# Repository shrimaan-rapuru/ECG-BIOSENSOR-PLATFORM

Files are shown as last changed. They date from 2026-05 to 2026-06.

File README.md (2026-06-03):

# Development and Evaluation of a Low-Cost Real-Time ECG Biosensing Platform

> Integrating Signal Processing, Robustness Analysis, and Physiological Visualization

**Shrimaan Rapuru** | The Early College at Guilford | Summer 2026
[Technical Report](report/) | [Results](results/) | [Dashboard](dashboard/)

---

## Abstract

This project investigates whether consumer-grade biosensing hardware can produce
physiologically meaningful cardiac metrics through optimized signal processing,
motivated by observed healthcare access inequality at Open Door Ministries, a
homeless shelter where I volunteer. Using a SparkFun AD8232 ECG module and Arduino
Uno R4 Minima ($102 total), I designed and validated a complete real-time ECG
acquisition and analysis pipeline. A 4th-order Butterworth bandpass filter
(0.5-40Hz) with IIR notch (60Hz) achieved visible PQRST morphology and 96.3%
mean R-peak detection accuracy across five validated resting trials. Three
structured experiments evaluated physiological response (resting vs. exercise vs.
recovery), electrode placement robustness, and comparative filter algorithm
performance. A key finding: Moving Average filtering achieves higher SNR but lower
detection reliability than Butterworth filtering, revealing that SNR alone is
insufficient to evaluate ECG filter quality. Results suggest low-cost ECG
acquisition is viable with careful signal processing methodology.

---

## Hero Figure

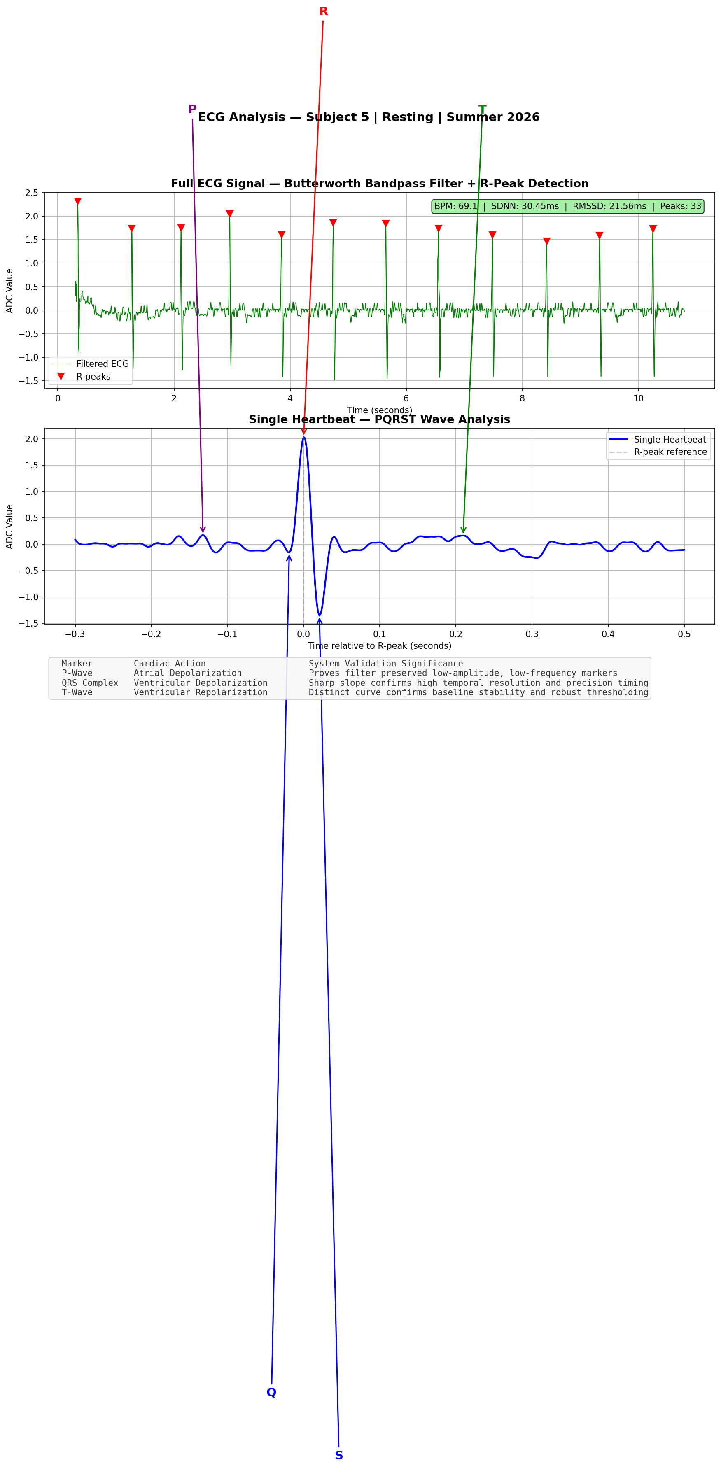
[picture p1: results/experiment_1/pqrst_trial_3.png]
PQRST Wave Analysis


*Real-time ECG signal captured at 533Hz. All 5 PQRST waves clearly identified.
BPM: 89.5 | SDNN: 17.63ms | RMSSD: 23.65ms | 42 peaks detected.*

---

## Why This Matters

Standard clinical ECG systems cost $1,000-$10,000, placing cardiac monitoring
out of reach for many individuals and resource-limited settings. This project
asks a practical engineering question: can a $102 consumer-grade system produce
physiologically meaningful cardiac metrics with careful signal processing?

The answer, supported by validated experiments, is yes. This work demonstrates
that accessibility and rigor are not mutually exclusive. The same engineering
discipline that produces expensive medical devices can be applied to low-cost
hardware to yield credible, reproducible physiological measurements.

This project was motivated by direct observation of healthcare access inequality
at Open Door Ministries, where I coordinate volunteer scheduling. Every system
I build asks the same question I first asked there: how do we build tools that
actually reach the people who need them most?

---

## Key Results

- 96.3% mean R-peak detection accuracy across 5 validated resting trials
- 20% post-exercise BPM elevation (90 to 108 BPM) with parasympathetic rebound confirmed
- All 5 PQRST waves visible: Q-wave 7.9% of R, S-wave 28.0% of R
- Single electrode displacement (+-2cm) has minimal BPM impact; combined displacement degrades accuracy 6.3%
- Moving Average achieves higher SNR but lower detection reliability than Butterworth -- confirming SNR alone is insufficient to evaluate ECG filter quality

---

## System Architecture

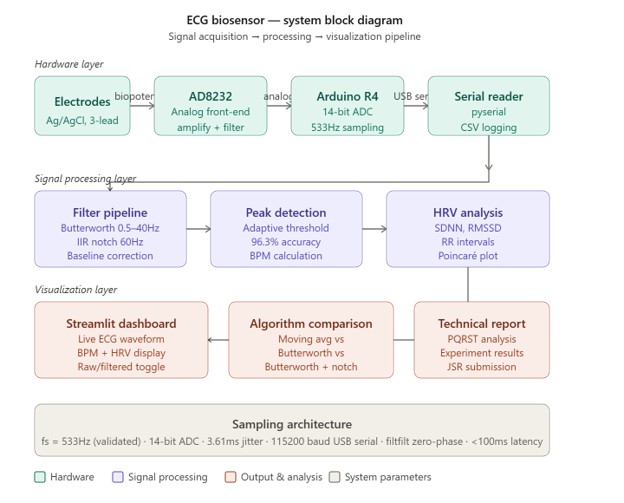
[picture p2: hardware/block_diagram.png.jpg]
Block Diagram


| Layer | Components |
|---|---|
| Hardware | AD8232 AFE -> Arduino R4 Minima (14-bit ADC, 533Hz) -> USB Serial |
| Signal Processing | Butterworth Bandpass (0.5-40Hz) + IIR Notch (60Hz) + Peak Detection |
| Analysis | BPM calculation, HRV (SDNN/RMSSD), PQRST morphology |
| Visualization | Streamlit live dashboard + Matplotlib experimental plots |

---

## Hardware

### Bill of Materials

| Component | Part Number | Cost | Purpose |
|---|---|---|---|
| SparkFun AD8232 | SEN-12650 | $24.41 | ECG analog front-end |
| Electrode Cable | CAB-12970 | $9.60 | 3-lead electrode connection |
| Arduino Uno R4 Minima | -- | $19.99 | 14-bit ADC + USB serial |
| Ag/AgCl Electrodes 100pk | Kendall | $15.30 | Skin contact |
| Breadboard + jumpers | -- | $8.99 | Prototyping |
| Alcohol prep pads | -- | $7.00 | Skin preparation |
| Header pins | HiLetgo 40-pin | $5.49 | AD8232 connection |
| **Total** | | **$90.78** | |

### Wiring

| AD8232 Pin | Arduino Pin | Function |
|---|---|---|
| 3.3V | 3.3V | Power |
| GND | GND | Ground |
| OUTPUT | A0 | ECG signal |
| LO+ | D10 | Lead-off detect + |
| LO- | D11 | Lead-off detect - |

### Hardware Photos

| | |
|---|---|
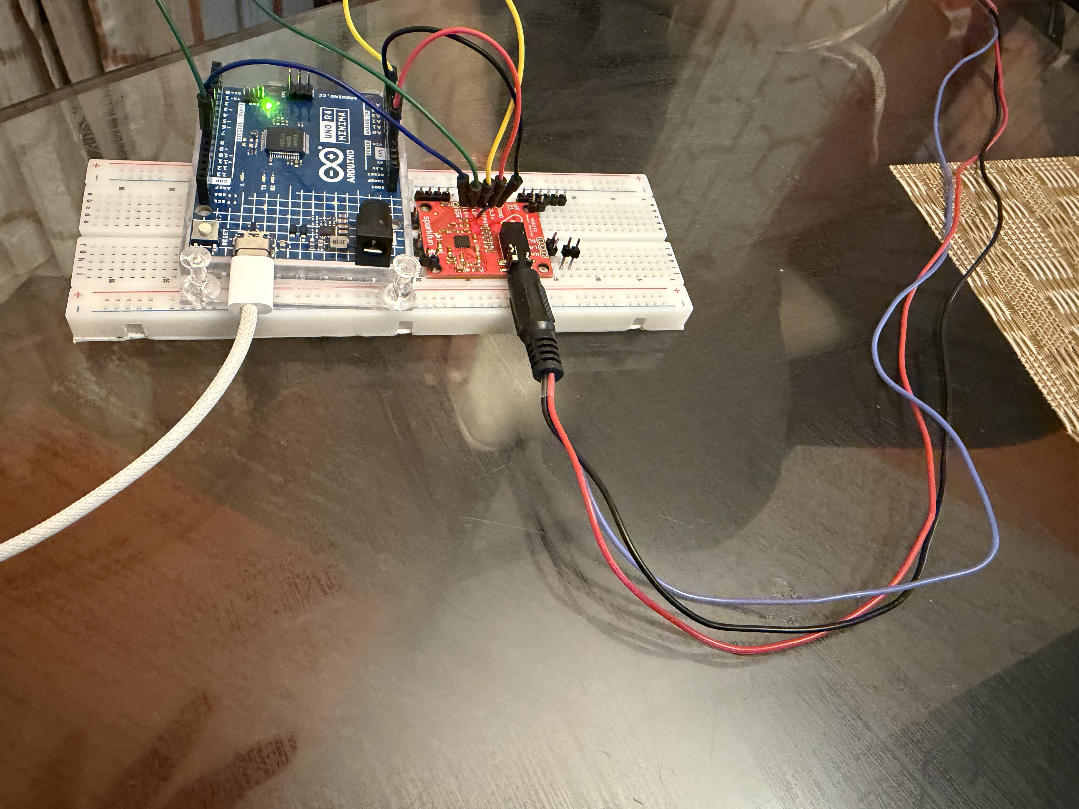
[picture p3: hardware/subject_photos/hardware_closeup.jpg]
Hardware
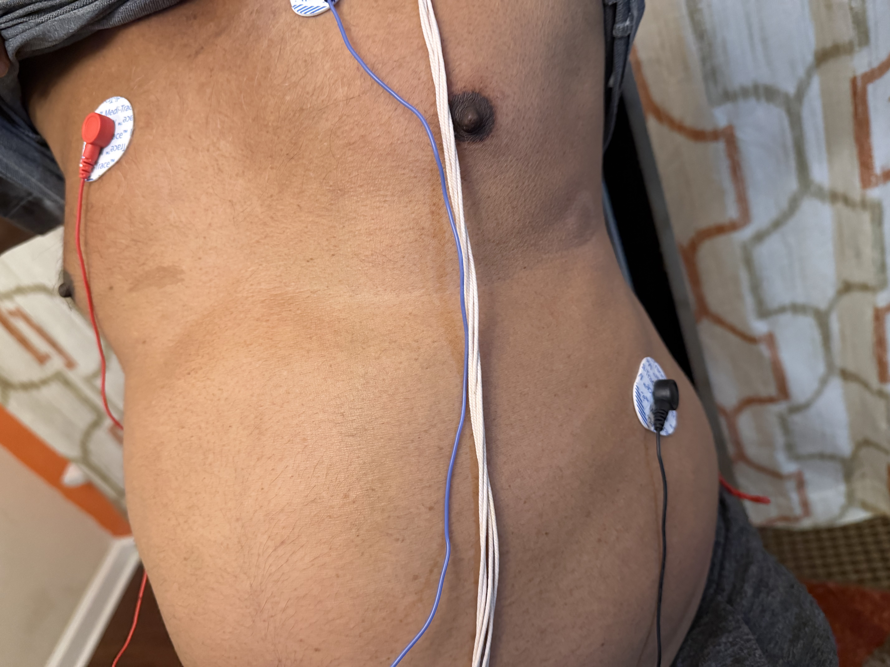
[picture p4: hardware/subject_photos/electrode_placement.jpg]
Electrodes
|  |  |
| Hardware setup — AD8232 + Arduino R4 Minima | Electrode placement on subject |
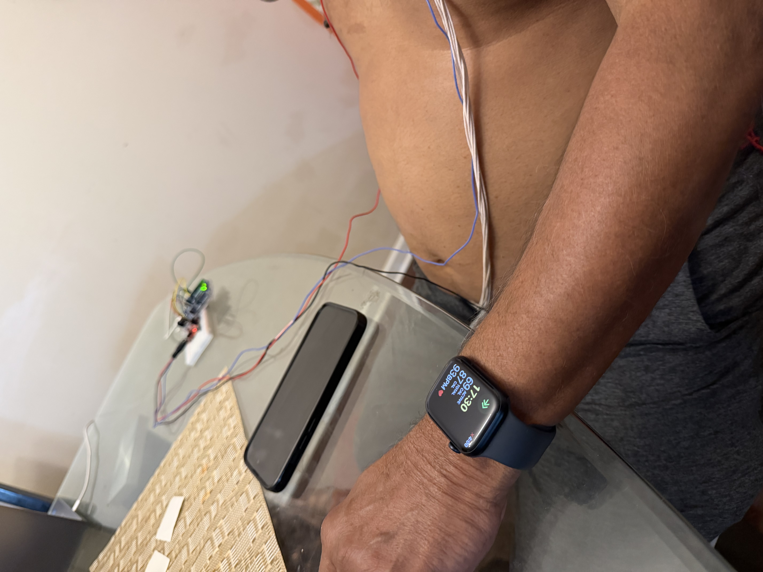
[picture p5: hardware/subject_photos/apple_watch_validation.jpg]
Validation
|  | Setup |
| Apple Watch BPM validation — simultaneous recording | Full system setup overview |
### Electrode Placement
- **Red** -> Right chest (below collarbone)
- **Blue** -> Left chest (below collarbone)
- **Black** -> Right lower abdomen (ground)

### PCB Design
Custom PCB designed in EasyEDA featuring AD8232, decoupling capacitors (2x100nF,
1x10uF), bias resistors (2x10kOhm), 3.5mm PJ-320A electrode jack, and Arduino
pin headers. All components selected from JLCPCB assembly library.
Fabrication via JLCPCB planned as Phase 2.

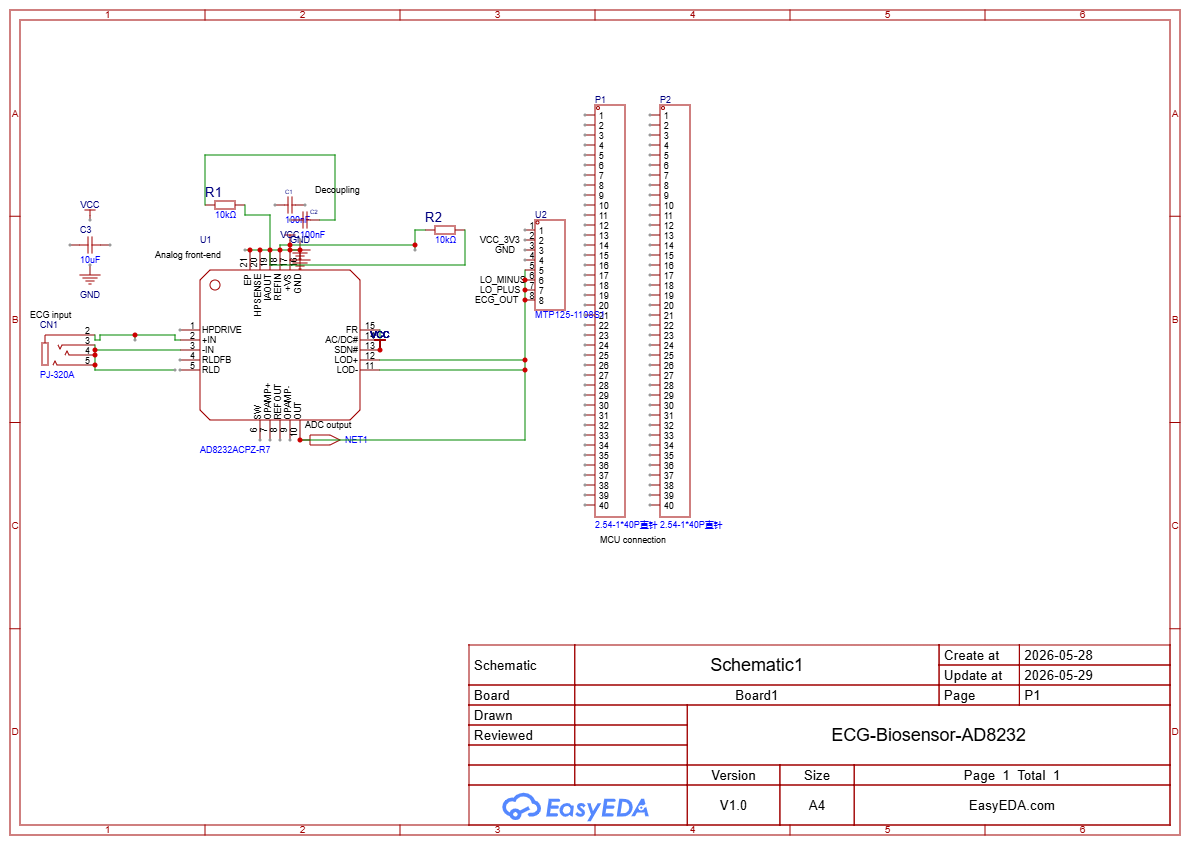
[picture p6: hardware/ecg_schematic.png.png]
Schematic


---

## Signal Processing Pipeline

### Filter Specifications

| Filter | Type | Cutoff | Order | Purpose |
|---|---|---|---|---|
| High-pass | Butterworth | 0.5 Hz | 4 | Baseline drift removal |
| Low-pass | Butterworth | 40 Hz | 4 | EMG artifact removal |
| Notch | IIR | 60 Hz | Q=30 | Powerline interference |

**Implementation:** Zero-phase filtering (scipy filtfilt) eliminates phase
distortion for accurate RR interval timing. Critical for HRV analysis where
millisecond-level timing precision determines metric validity.

**Design decision:** The 0.5 Hz lower cutoff was deliberately calibrated to
preserve the low-amplitude P-wave rather than aggressively filtering baseline
drift -- prioritizing physiological completeness over visual cleanliness.

### Sampling Architecture

| Parameter | Value |
|---|---|
| Sampling frequency | 533.3 Hz (validated -- not assumed) |
| ADC resolution | 14-bit |
| Serial baud rate | 115200 bps |
| Timing jitter | 3.61ms |
| Recording duration | 30 seconds (16,000 samples) |
| Signal inversion | Applied (electrode polarity correction) |

### Peak Detection

Adaptive threshold: median + 0.5 x std
Minimum R-R distance: 0.6 x fs (prevents double detection)
Mean accuracy: 96.3% (range: 89.4%-100.0%, N=5 trials)

### Key Signal Processing Insight

A critical finding from Experiment 3: Moving Average filtering achieved higher
mean SNR (0.63 +/- 1.99 dB) compared to Butterworth bandpass (-10.14 +/- 3.58 dB),
yet demonstrated inferior BPM consistency across trials.

This reveals a fundamental limitation of SNR as an ECG filter evaluation metric:
- Moving Average smooths broadband noise but distorts QRS morphology
- Butterworth bandpass selectively removes non-physiological frequency content
- Visually cleaner signals are not necessarily physiologically superior
- Morphology preservation matters more than signal power ratio for reliable detection

Filter Comparison

### PQRST Morphology

| Wave | Amplitude | % of R | Physiological Meaning |
|---|---|---|---|
| P | visible | -- | Atrial depolarization |
| Q | -18.0 ADC | 7.9% | Septal depolarization |
| R | 228.3 ADC | 100% | Ventricular depolarization |
| S | -64.0 ADC | 28.0% | Late ventricular depolarization |
| T | ~50 ADC | ~22% | Ventricular repolarization |

---

## Experiments

### Experiment 1 -- Resting vs Exercise vs Recovery

| State | BPM | SDNN | RMSSD |
|---|---|---|---|
| Resting avg | 91.0 | 41.31ms | 45.93ms |
| Pre-exercise | 90 | -- | -- |
| Post-exercise | 108 | -- | -- |
| Recovery 1 | 86.7 | 54.33ms | 45.45ms |
| Recovery 2 | 92.1 | 20.18ms | 9.91ms |
| Recovery 3 | 95.7 | 9.24ms | 9.42ms |

### Experiment 2 -- Electrode Placement Robustness

| Condition | Avg BPM | vs Standard |
|---|---|---|
| Standard | 82.2 | baseline |
| RA off 2cm | 81.6 | -0.7% |
| LA off 2cm | 83.0 | +1.0% |
| Both off 2cm | 87.4 | +6.3% |

### Experiment 3 -- Filter Algorithm Comparison

| Algorithm | SNR | BPM | Time |
|---|---|---|---|
| Moving Average | 0.63 +/- 1.99 dB | 88.02 +/- 8.08 | 0.69ms |
| Butterworth | -10.14 +/- 3.58 dB | 80.14 +/- 22.04 | 4.4ms |
| Butterworth+Notch | -10.16 +/- 3.58 dB | 79.7 +/- 22.92 | 2.11ms |

---

## Live Dashboard

Dashboard

**Features:**
- Real-time ECG waveform with R-peak markers
- Live BPM display (color-coded red if >100 BPM)
- SDNN and RMSSD updating in real time
- Raw vs filtered signal toggle
- Lead-off detection alert
- CSV export for offline analysis

**Run locally:**

```
cd dashboard
pip install -r requirements.txt
streamlit run ecg_dashboard.py
```

> Not a medical device. For educational and research purposes only.

---

## Installation

```
pip install streamlit pandas numpy scipy pyserial plotly matplotlib
```

Arduino setup: Install Arduino IDE 2.x, select Arduino UNO R4 Minima,
set baud rate 115200, close Serial Monitor before running Python scripts.

---

## Repository Structure

```
ecg-biosensor/
├── signal_processing/           # Python analysis scripts
│   ├── serial_reader.py         # Arduino serial data capture
│   ├── filters.py               # Butterworth + notch filter pipeline
│   ├── peak_detection.py        # R-peak detection + HRV analysis
│   ├── pqrst_analysis.py        # PQRST wave visualization
│   ├── raw_vs_filtered.py       # Normalized comparison plots
│   ├── negative_deflection.py   # Q/S wave investigation
│   ├── filter_visual_comparison.py  # 4-panel algorithm comparison
│   ├── experiment_3.py          # Algorithm benchmarking
│   ├── quick_bpm_check.py       # 10-second live BPM check
│   └── validation.py            # Peak accuracy validation
├── dashboard/                   # Streamlit live dashboard
│   ├── ecg_dashboard.py
│   └── requirements.txt
├── results/                     # All experimental data and plots
│   ├── experiment_1/            # Resting/exercise/recovery (10 trials)
│   ├── experiment_2/            # Electrode placement (12 trials)
│   └── experiment_3/            # Filter comparison (15 trials)
├── hardware/                    # PCB design and documentation
│   ├── ecg_schematic.png
│   ├── block_diagram.png
│   └── dashboard_screenshots/
└── report/                      # Technical report and references
    └── references/              # 5 peer-reviewed papers
```

---

## Limitations

- **Single subject:** All data from one subject -- findings cannot be generalized
- **Short HRV windows:** 30-second recordings below the 5-minute clinical standard
- **Motion artifact:** Post-exercise filtered-pipeline recordings were unreliable
- **SNR methodology:** Standard SNR penalizes DC attenuation -- may not reflect morphology quality
- **Breadboard connections:** Mechanical instability motivates PCB fabrication

---

## Future Work

- [ ] Custom PCB fabrication via JLCPCB (schematic complete)
- [ ] Multi-subject validation study (N>=10)
- [ ] Streamlit Cloud deployment
- [ ] 5-minute HRV recording windows
- [ ] lfilter for real-time causal filtering
- [ ] Bland-Altman analysis vs commercial pulse oximeter
- [ ] Journal of Student Research submission (August 2026)

---

## References

1. Pan, J. & Tompkins, W.J. (1985). A real-time QRS detection algorithm. IEEE Trans Biomed Eng, 32(3), 230-236.
2. Task Force of ESC & NASPE (1996). Heart rate variability standards. Circulation, 93(5), 1043-1065.
3. Serhani, M.A. et al. (2020). ECG monitoring systems review. Sensors, 20(6), 1796.
4. Kohler, B.U. et al. (2002). Software QRS detection principles. IEEE Eng Med Biol, 21(1), 42-57.
5. Christov, I.I. (2004). Real time QRS detection adaptive threshold. BioMed Eng OnLine, 3(1), 28.

---

## License

MIT License -- see LICENSE for details.

---

## About

This project was motivated by observations at Open Door Ministries, a homeless
shelter where I volunteer as scheduling coordinator. Witnessing healthcare access
inequality firsthand raised a question that drove this research: can low-cost
consumer hardware produce clinically meaningful cardiac metrics with careful
signal processing? The answer, supported by validated experiments, is yes.

> "Every project I pursue asks the same question I first asked at Open Door:
> how do we build systems that actually reach the people who need them most?"

Shrimaan Rapuru | The Early College at Guilford, NC

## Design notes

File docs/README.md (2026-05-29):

# Documentation

- [Technical Report](technical_report.pdf) — coming soon
- [Block Diagram](../hardware/block_diagram.png)
- [PCB Schematic](../hardware/ecg_schematic.png)
- [System Architecture](../hardware/block_diagram.png)

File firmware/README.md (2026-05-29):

# Firmware

Arduino sketch for ECG data acquisition.

## Setup
- Board: Arduino UNO R4 Minima
- Baud rate: 115200
- Sampling rate: 533Hz (validated)

## Pin Configuration
- A0: ECG signal output from AD8232
- D10: Lead-off detection LO+
- D11: Lead-off detection LO-
- 3.3V: Power to AD8232
- GND: Ground

## Arduino Code

```cpp
void setup() {
  Serial.begin(115200);
  pinMode(10, INPUT);
  pinMode(11, INPUT);
}

void loop() {
  if (digitalRead(10) == 1 || digitalRead(11) == 1) {
    Serial.println('!');
  } else {
    Serial.println(analogRead(A0));
  }
}
```

## Notes
- Close Serial Monitor/Plotter before running Python scripts
- Actual sampling rate is 533Hz due to Arduino R4 Minima 48MHz processor
- Signal is inverted due to electrode polarity -- corrected in software

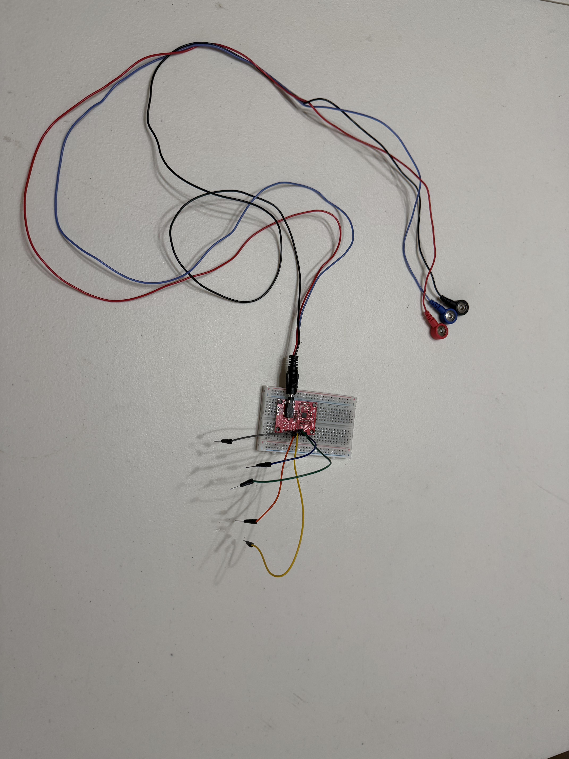
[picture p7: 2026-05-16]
hardware/ad8232_connections.jpg.jpeg

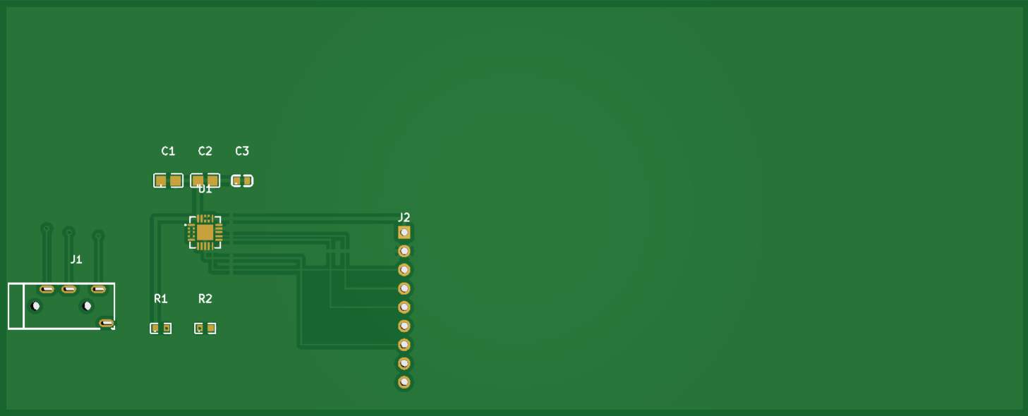
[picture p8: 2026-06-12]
hardware/pcb_renders/final_pcb_design.png

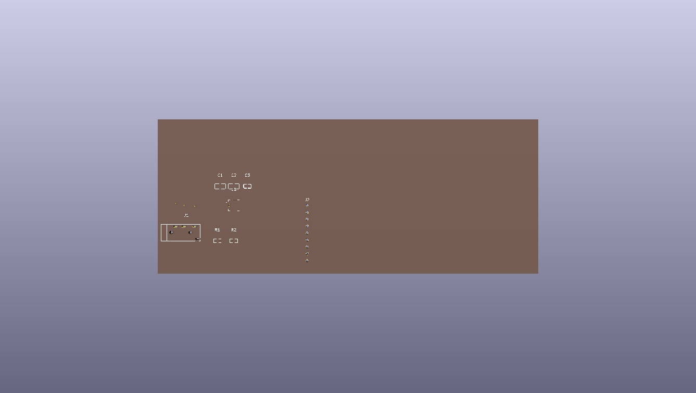
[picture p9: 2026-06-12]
hardware/pcb_renders/ECG-Biosensor-AD8232-final photo.png

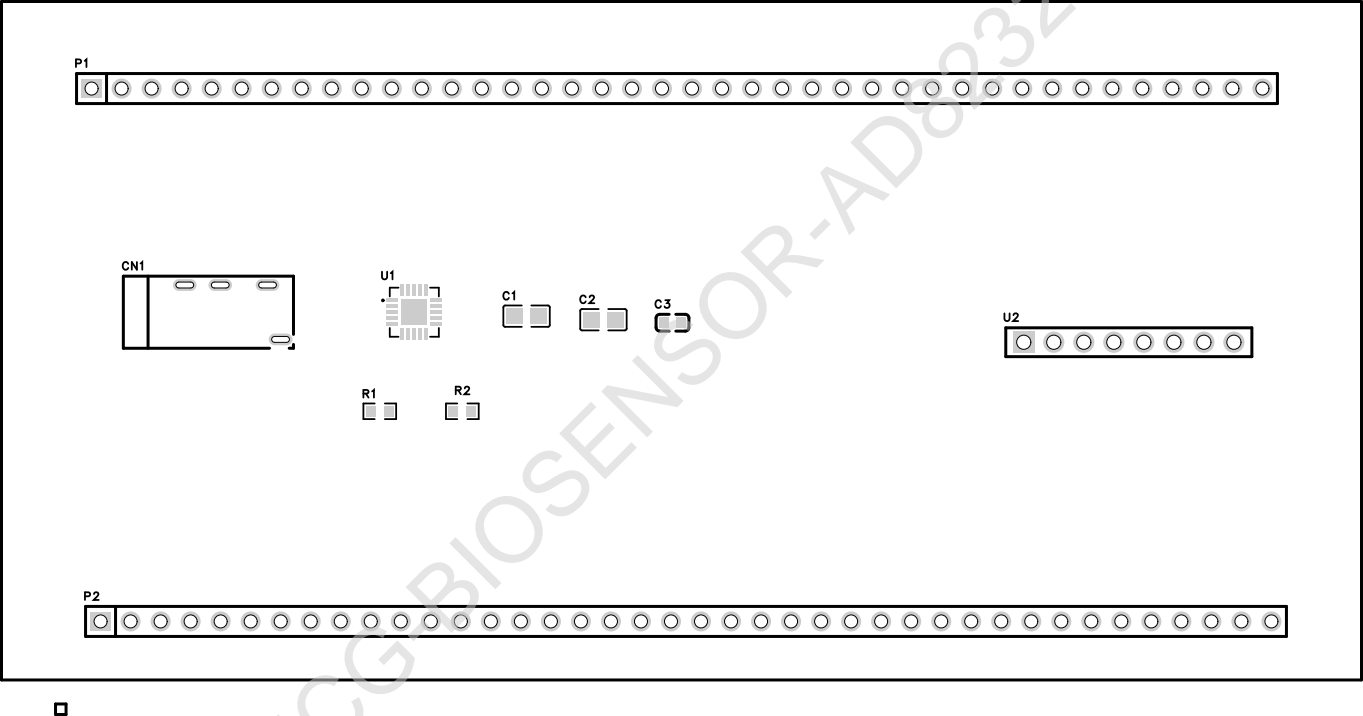
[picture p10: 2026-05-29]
hardware/ecg_pcb_layout1.png

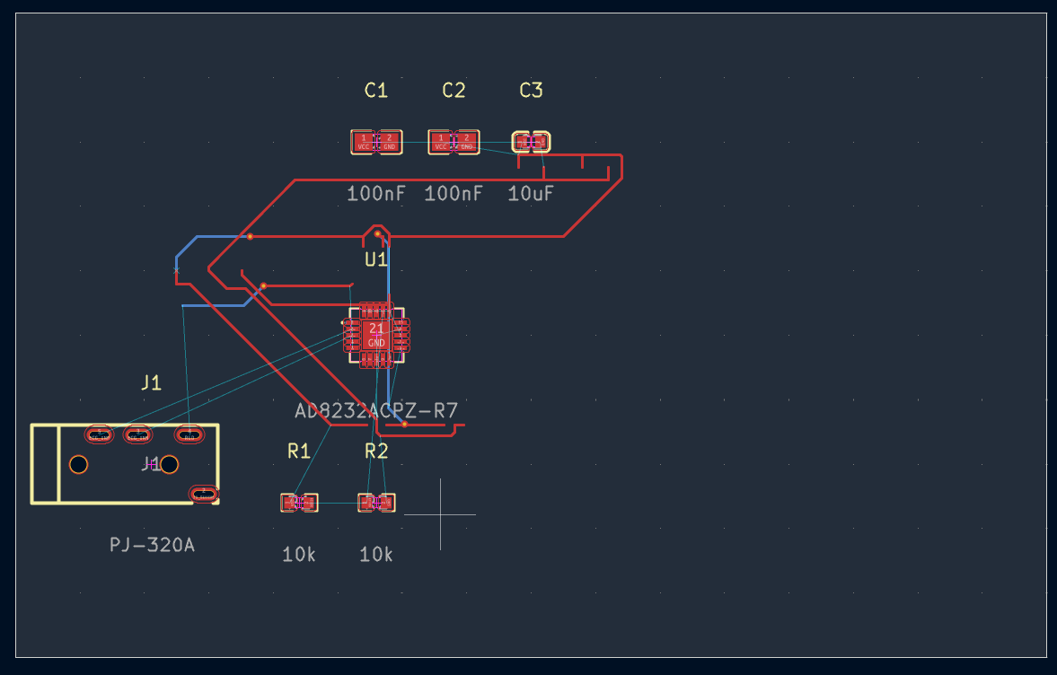
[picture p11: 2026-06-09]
hardware/ecg_pcb_layout.png

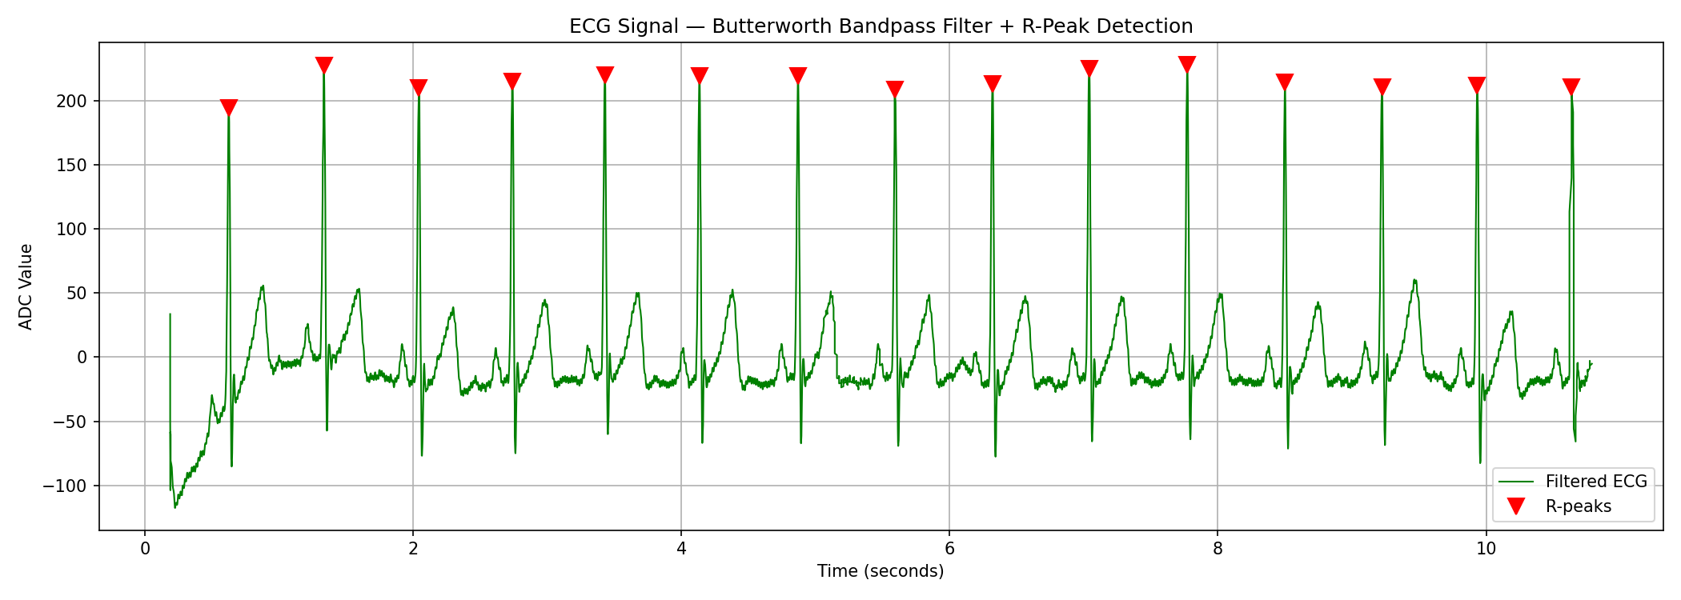
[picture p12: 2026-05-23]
signal_processing/ecg_filtered_peaks.png

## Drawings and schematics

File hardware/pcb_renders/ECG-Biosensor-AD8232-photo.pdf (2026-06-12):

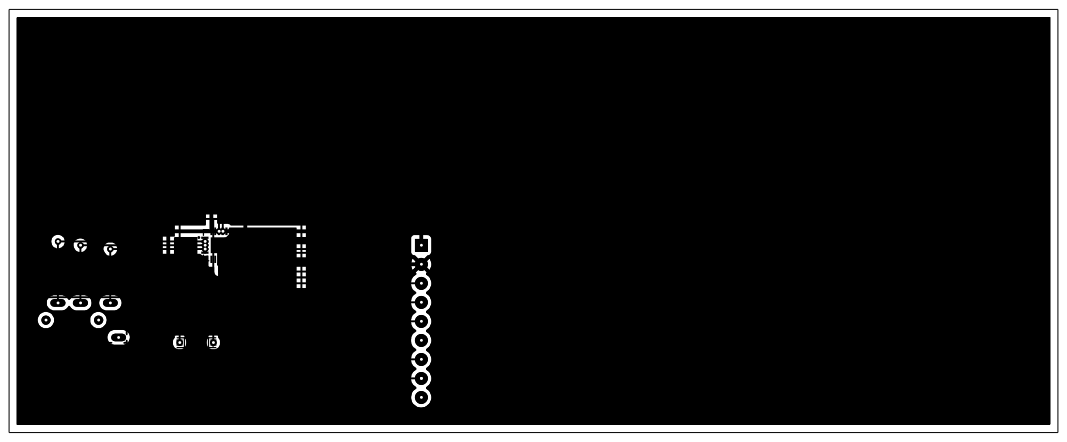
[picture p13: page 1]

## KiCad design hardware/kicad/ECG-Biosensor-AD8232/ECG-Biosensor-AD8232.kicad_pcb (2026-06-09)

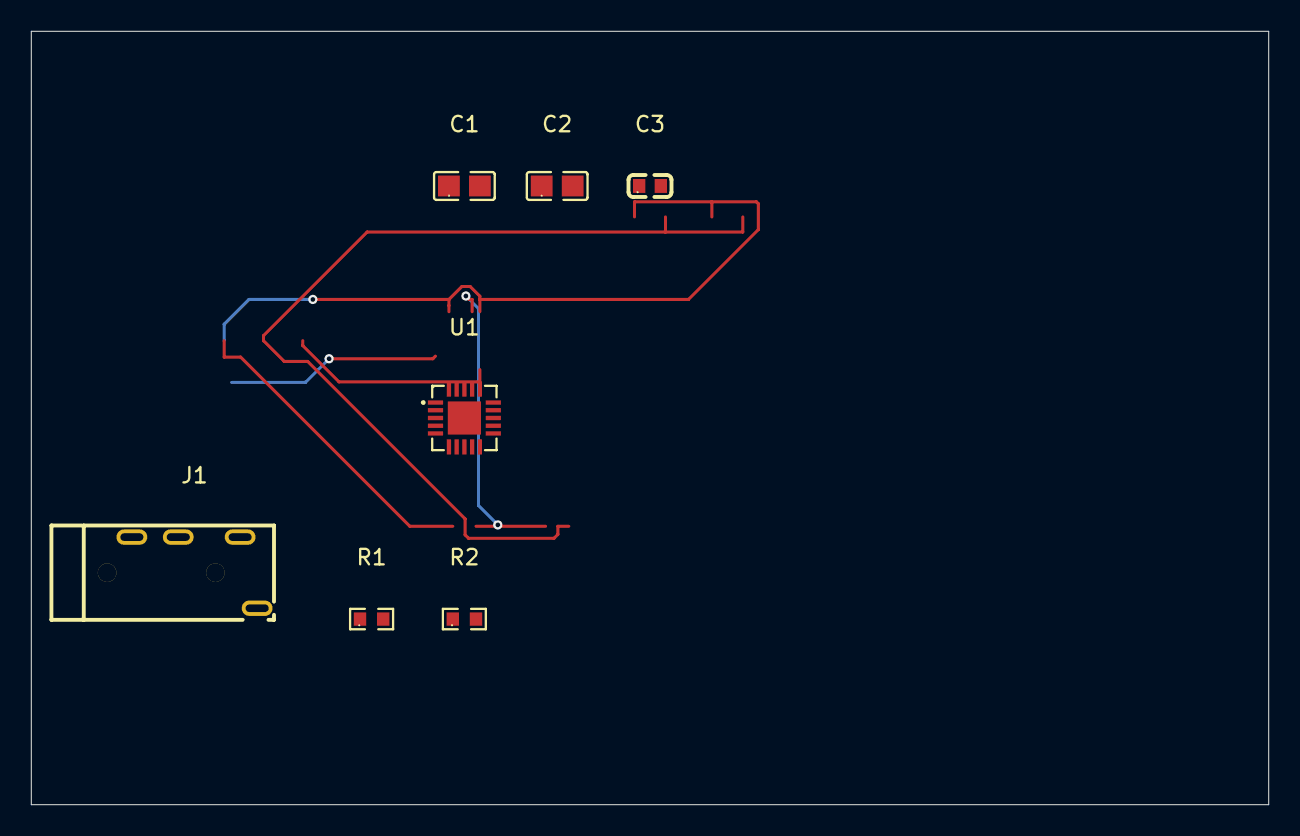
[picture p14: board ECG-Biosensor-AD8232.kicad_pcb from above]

Board: 2 copper layers, 80.0 x 50.0 mm, 7 parts (0 on the bottom side), 6 nets.

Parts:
C1, C2: 100nF; C0805
C3: 10uF; C0603
J1: PJ-320A; AUDIO-TH_PJ-320A_C49284721
R1, R2: 10k; R0603
U1: AD8232ACPZ-R7; LFCSP-20_L4.0-W4.0-P0.50-TL-EP2.7

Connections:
ECG_INN: J1.3, U1.3
ECG_INP: J1.5, U1.2
GND: C1.2, C2.2, C3.2, R2.2, U1.14, U1.21
REFIN: R1.2, R2.1, U1.17
RLD: J1.4, U1.4, U1.5
VCC: C1.1, C2.1, C3.1, R1.1, U1.13, U1.16, U1.20

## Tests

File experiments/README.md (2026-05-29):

# Experiments

## Experiment 1 — Resting vs Exercise vs Recovery
- Protocol: 5 resting trials + 3 exercise blocks
- Results: [experiment_1/](../results/experiment_1/)

## Experiment 2 — Electrode Placement Robustness  
- Protocol: 4 conditions x 3 trials
- Results: [experiment_2/](../results/experiment_2/)

## Experiment 3 — Filter Algorithm Comparison
- Protocol: 3 algorithms x 5 trials
- Results: [experiment_3/](../results/experiment_3/)

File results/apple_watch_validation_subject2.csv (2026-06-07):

Subject | Reading | Apple_Watch_BPM | ECG_System_BPM | Difference
Subject_2 | 1 | 98 | 108 | 10
Subject_2 | 2 | 96 | 96 | 0
Subject_2 | 3 | 94 | 96 | 2
Subject_2 | 4 | 100 | 96 | -4
Subject_2 | 5 | 99 | 96 | -3

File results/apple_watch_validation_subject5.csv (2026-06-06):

Subject | Reading | Apple_Watch_BPM | ECG_System_BPM | Difference
Subject_5 | 1 | 67 | 78 | 11
Subject_5 | 2 | 76 | 84 | 8
Subject_5 | 3 | 72 | 84 | 12
Subject_5 | 4 | 70 | 84 | 14
Subject_5 | 5 | 75 | 90 | 15

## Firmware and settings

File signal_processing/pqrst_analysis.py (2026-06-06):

import numpy as np
import pandas as pd
import matplotlib.pyplot as plt
from scipy.signal import butter, filtfilt, find_peaks

def butter_bandpass_filter(data, lowcut=0.5, highcut=40.0, fs=533, order=4):
    nyq = 0.5 * fs
    b, a = butter(order, [lowcut / nyq, highcut / nyq], btype='band')
    return filtfilt(b, a, data)

def plot_pqrst(trial_num=3, fs=533):
    # Load data
    df = pd.read_csv('../results/experiment_1/subject_5_pqrst_trial.csv')
    raw = df['ecg_value'].values.astype(float)
    timestamps = df['timestamp'].values

    # Preprocess
    skip = int(2 * fs)
    raw = raw[skip:]
    timestamps = timestamps[skip:]
    raw = np.clip(raw, np.percentile(raw, 1), np.percentile(raw, 99))
    raw = -raw

    # Filter
    filtered = butter_bandpass_filter(raw, fs=fs)

    # Detect R-peaks
    peaks, _ = find_peaks(filtered,
                          distance=int(0.6 * fs),
                          height=np.median(filtered) + 0.5 * np.std(filtered))

    if len(peaks) < 3:
        print("Not enough peaks detected")
        return

    # ── SINGLE BEAT ZOOM ─────────────────────────────────
    # Pick cleanest peak — highest amplitude in middle of recording
    middle_peaks = peaks[len(peaks)//4 : 3*len(peaks)//4]
    center_peak = middle_peaks[np.argmax(filtered[middle_peaks])]

    # Window: 0.3s before R-peak, 0.5s after
    pre  = int(0.3 * fs)
    post = int(0.5 * fs)
    start = center_peak - pre
    end   = center_peak + post

    if start < 0 or end > len(filtered):
        center_peak = peaks[len(peaks)//2]
        start = center_peak - pre
        end   = center_peak + post

    # Extract single beat
    beat = filtered[start:end]
    t_beat = np.linspace(-0.3, 0.5, len(beat))  # Time relative to R-peak

    # ── IDENTIFY PQRST COMPONENTS ────────────────────────
    r_idx = pre  # R-peak is at index 'pre' in the beat window

    # P wave — search 0.1 to 0.25s before R-peak
    p_search_start = r_idx - int(0.25 * fs)
    p_search_end   = r_idx - int(0.08 * fs)
    p_search_start = max(0, p_search_start)
    p_region = beat[p_search_start:p_search_end]
    p_idx = p_search_start + np.argmax(p_region)

    # Q wave — small dip just before R (0.02-0.08s before R)
    q_search_start = r_idx - int(0.08 * fs)
    q_search_end   = r_idx - int(0.01 * fs)
    q_search_start = max(0, q_search_start)
    q_region = beat[q_search_start:q_search_end]
    q_idx = q_search_start + np.argmin(q_region)

    # S wave — small dip just after R (0.02-0.08s after R)
    s_search_start = r_idx + int(0.01 * fs)
    s_search_end   = r_idx + int(0.08 * fs)
    s_search_end   = min(len(beat), s_search_end)
    s_region = beat[s_search_start:s_search_end]
    s_idx = s_search_start + np.argmin(s_region)

    # T wave — broad peak 0.15 to 0.4s after R
    t_search_start = r_idx + int(0.15 * fs)
    t_search_end   = r_idx + int(0.40 * fs)
    t_search_end   = min(len(beat), t_search_end)
    t_region = beat[t_search_start:t_search_end]
    t_idx = t_search_start + np.argmax(t_region)

    # ── PLOT ─────────────────────────────────────────────
    fig, axes = plt.subplots(2, 1, figsize=(14, 10))

    # ── TOP: Full 10-second filtered signal ──────────────
    s10 = fs * 10
    axes[0].plot(timestamps[:s10], filtered[:s10],
                 color='green', linewidth=0.8, label='Filtered ECG')
    peaks_in_window = peaks[peaks < s10]
    axes[0].plot(timestamps[peaks_in_window], filtered[peaks_in_window],
                 'rv', markersize=8, label='R-peaks')
    axes[0].set_title('Full ECG Signal — Butterworth Bandpass Filter + R-Peak Detection',
                      fontsize=13, fontweight='bold')
    axes[0].set_ylabel('ADC Value')
    axes[0].set_xlabel('Time (seconds)')
    axes[0].legend()
    axes[0].grid(True)

    # BPM and HRV annotation
    rr = np.diff(peaks) / fs * 1000
    bpm = round(60 / (np.mean(np.diff(peaks)) / fs), 1)
    sdnn = round(np.std(rr), 2)
    rmssd = round(np.sqrt(np.mean(np.diff(rr)**2)), 2)
    axes[0].text(0.98, 0.95,
                 f'BPM: {bpm}  |  SDNN: {sdnn}ms  |  RMSSD: {rmssd}ms  |  Peaks: {len(peaks)}',
                 transform=axes[0].transAxes,
                 fontsize=10, ha='right', va='top',
                 bbox=dict(boxstyle='round', facecolor='lightgreen', alpha=0.8))

    # ── BOTTOM: Single beat PQRST zoom ───────────────────
    axes[1].plot(t_beat, beat, color='blue', linewidth=2.0, label='Single Heartbeat')
    axes[1].axvline(x=0, color='gray', linestyle='--', alpha=0.4, label='R-peak reference')

    # Annotate each wave
    wave_color = 'red'
    offset = 8  # vertical offset for labels

    axes[1].annotate('P', xy=(t_beat[p_idx], beat[p_idx]),
                     xytext=(t_beat[p_idx]-0.02, beat[p_idx]+offset),
                     fontsize=14, fontweight='bold', color='purple',
                     arrowprops=dict(arrowstyle='->', color='purple', lw=1.5))

    axes[1].annotate('Q', xy=(t_beat[q_idx], beat[q_idx]),
                     xytext=(t_beat[q_idx]-0.03, beat[q_idx]-offset*2),
                     fontsize=14, fontweight='bold', color='blue',
                     arrowprops=dict(arrowstyle='->', color='blue', lw=1.5))

    axes[1].annotate('R', xy=(t_beat[r_idx], beat[r_idx]),
                     xytext=(t_beat[r_idx]+0.02, beat[r_idx]+offset),
                     fontsize=14, fontweight='bold', color='red',
                     arrowprops=dict(arrowstyle='->', color='red', lw=1.5))

    axes[1].annotate('S', xy=(t_beat[s_idx], beat[s_idx]),
                     xytext=(t_beat[s_idx]+0.02, beat[s_idx]-offset*2),
                     fontsize=14, fontweight='bold', color='blue',
                     arrowprops=dict(arrowstyle='->', color='blue', lw=1.5))

    axes[1].annotate('T', xy=(t_beat[t_idx], beat[t_idx]),
                     xytext=(t_beat[t_idx]+0.02, beat[t_idx]+offset),
                     fontsize=14, fontweight='bold', color='green',
                     arrowprops=dict(arrowstyle='->', color='green', lw=1.5))

    axes[1].set_title('Single Heartbeat — PQRST Wave Analysis',
                      fontsize=13, fontweight='bold')
    axes[1].set_xlabel('Time relative to R-peak (seconds)')
    axes[1].set_ylabel('ADC Value')
    axes[1].legend()
    axes[1].grid(True)

    # Add wave descriptions
    axes[1].text(0.01, -0.18,
             '  Marker        Cardiac Action                    '
             'System Validation Significance\n'
             '  P-Wave        Atrial Depolarization             '
             'Proves filter preserved low-amplitude, low-frequency markers\n'
             '  QRS Complex   Ventricular Depolarization        '
             'Sharp slope confirms high temporal resolution and precision timing\n'
             '  T-Wave        Ventricular Repolarization        '
             'Distinct curve confirms baseline stability and robust thresholding',
             transform=axes[1].transAxes,
             fontsize=10, color='#333333', va='top',
             fontfamily='monospace',
             bbox=dict(boxstyle='round', facecolor='#f8f8f8',
                      edgecolor='#cccccc', alpha=0.9))

    plt.suptitle(f'ECG Analysis — Subject 5 | Resting | Summer 2026',
                 fontsize=14, fontweight='bold', y=1.01)
    plt.tight_layout()
    plt.subplots_adjust(bottom=0.18)
    plt.savefig(f'../results/experiment_1/pqrst_trial_{trial_num}.png',
                dpi=150, bbox_inches='tight')
    print(f"PQRST plot saved to results/experiment_1/pqrst_trial_{trial_num}.png")
    print(f"BPM: {bpm} | SDNN: {sdnn}ms | RMSSD: {rmssd}ms")
    plt.show()

if __name__ == "__main__":
    plot_pqrst(trial_num=3)  # Use Trial 3 — your cleanest trial

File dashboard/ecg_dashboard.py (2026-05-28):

import streamlit as st
import serial
import serial.tools.list_ports
import numpy as np
import pandas as pd
import time
import csv
from datetime import datetime
from collections import deque
from scipy.signal import butter, filtfilt, find_peaks
import plotly.graph_objects as go

# ── PAGE CONFIG ───────────────────────────────────────────
st.set_page_config(
    page_title="ECG Biosensor Dashboard",
    page_icon="❤️",
    layout="wide"
)

# ── CUSTOM CSS ────────────────────────────────────────────
st.markdown("""
<style>
    .bpm-display {
        font-size: 80px;
        font-weight: bold;
        color: #e74c3c;
        text-align: center;
    }
    .hrv-display {
        font-size: 40px;
        font-weight: bold;
        color: #2ecc71;
        text-align: center;
    }
    .metric-label {
        font-size: 18px;
        color: #888888;
        text-align: center;
    }
    .lead-off {
        font-size: 24px;
        font-weight: bold;
        color: white;
        background-color: #e74c3c;
        padding: 10px;
        border-radius: 5px;
        text-align: center;
    }
    .connected {
        font-size: 18px;
        color: #2ecc71;
        font-weight: bold;
    }
</style>
""", unsafe_allow_html=True)

# ── FILTER FUNCTIONS ──────────────────────────────────────
def butter_bandpass(data, lowcut=0.5, highcut=40.0, fs=533, order=4):
    nyq = 0.5 * fs
    b, a = butter(order, [lowcut/nyq, highcut/nyq], btype='band')
    return filtfilt(b, a, data)

def full_pipeline(data, fs=533):
    from scipy.signal import iirnotch
    nyq = 0.5 * fs
    b_notch, a_notch = iirnotch(60/nyq, 30)
    filtered = butter_bandpass(data, fs=fs)
    filtered = filtfilt(b_notch, a_notch, filtered)
    return filtered

def detect_peaks(filtered, fs=533):
    if len(filtered) < int(fs * 2):
        return np.array([])
    peaks, _ = find_peaks(filtered,
                          distance=int(0.6 * fs),
                          height=np.median(filtered) + 0.5 * np.std(filtered))
    return peaks

def calculate_bpm(peaks, fs=533):
    if len(peaks) < 2:
        return 0
    rr = np.diff(peaks) / fs
    return round(60 / np.mean(rr), 1)

def calculate_hrv(peaks, fs=533):
    if len(peaks) < 3:
        return 0, 0
    rr = np.diff(peaks) / fs * 1000
    sdnn = round(np.std(rr), 2)
    rmssd = round(np.sqrt(np.mean(np.diff(rr)**2)), 2)
    return sdnn, rmssd

# ── SIDEBAR ───────────────────────────────────────────────
st.sidebar.title("⚙️ Settings")

# Port selection
ports = [p.device for p in serial.tools.list_ports.comports()]
if not ports:
    ports = ["COM3"]
selected_port = st.sidebar.selectbox("Serial Port", ports, index=0)

fs = st.sidebar.number_input("Sampling Rate (Hz)", value=533, min_value=100, max_value=1000)
window_size = st.sidebar.slider("Display Window (seconds)", 5, 30, 10)
show_raw = st.sidebar.checkbox("Show Raw Signal", value=False)
subject_name = st.sidebar.text_input("Subject ID", value="Subject 2")

st.sidebar.markdown("---")
st.sidebar.markdown("**Filter Settings:**")
st.sidebar.markdown("- Butterworth Bandpass: 0.5–40 Hz")
st.sidebar.markdown("- IIR Notch: 60 Hz")
st.sidebar.markdown("- Order: 4")
st.sidebar.markdown("- Zero-phase (filtfilt)")

# ── MAIN TITLE ────────────────────────────────────────────
st.title("❤️ Real-Time ECG Biosensor Dashboard")
st.markdown("**Low-Cost ECG Signal Acquisition & HRV Analysis Platform**")
st.markdown(f"*Subject: {subject_name} | Port: {selected_port} | fs: {fs}Hz*")

# ── LEAD OFF ALERT (placeholder) ─────────────────────────
lead_off_placeholder = st.empty()

# ── METRICS ROW ───────────────────────────────────────────
col1, col2, col3, col4 = st.columns(4)

with col1:
    st.markdown('<p class="metric-label">Heart Rate</p>', unsafe_allow_html=True)
    bpm_placeholder = st.empty()

with col2:
    st.markdown('<p class="metric-label">SDNN</p>', unsafe_allow_html=True)
    sdnn_placeholder = st.empty()

with col3:
    st.markdown('<p class="metric-label">RMSSD</p>', unsafe_allow_html=True)
    rmssd_placeholder = st.empty()

with col4:
    st.markdown('<p class="metric-label">Peaks Detected</p>', unsafe_allow_html=True)
    peaks_placeholder = st.empty()

st.markdown("---")

# ── ECG CHART ─────────────────────────────────────────────
st.subheader("📈 ECG Waveform")
chart_placeholder = st.empty()

st.markdown("---")

# ── CONTROLS ──────────────────────────────────────────────
col_start, col_stop, col_save = st.columns(3)

with col_start:
    start_btn = st.button("▶️ Start Recording", type="primary")
with col_stop:
    stop_btn = st.button("⏹️ Stop Recording")
with col_save:
    save_btn = st.button("💾 Save CSV")
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

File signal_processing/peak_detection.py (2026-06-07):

import pandas as pd
import numpy as np
from scipy.signal import find_peaks
from filters import full_pipeline
import matplotlib.pyplot as plt

def detect_r_peaks(filtered_signal, fs=533):
    min_distance = int(0.6 * fs)
    threshold = np.median(filtered_signal) + 0.5 * np.std(filtered_signal)
    peaks, _ = find_peaks(filtered_signal, distance=min_distance, height=threshold)
    return peaks

def calculate_bpm(peaks, fs=533):
    if len(peaks) < 2:
        return 0
    rr_intervals = np.diff(peaks) / fs
    return round(60 / np.mean(rr_intervals), 1)

def compute_hrv(peaks, fs=533):
    if len(peaks) < 3:
        return None
    rr = np.diff(peaks) / fs * 1000
    return {'SDNN_ms': round(np.std(rr), 2), 'RMSSD_ms': round(np.sqrt(np.mean(np.diff(rr)**2)), 2), 'mean_RR_ms': round(np.mean(rr), 2), 'num_beats': len(peaks)}
def plot_single_beat(filtered, peaks, timestamps, fs=533):
    if len(peaks) < 3:
        return
    center_peak = peaks[len(peaks)//2]
    start = center_peak - int(0.3 * fs)
    end = center_peak + int(0.5 * fs)
    if start < 0 or end > len(filtered):
        return
    t = timestamps[start:end]
    f = filtered[start:end]
    t_relative = t - t[0]
    r_peak_time = t_relative[int(0.3 * fs)]
    plt.figure(figsize=(10, 5))
    plt.plot(t_relative, f, color='blue', linewidth=1.5)
    plt.axvline(x=r_peak_time, color='red', linestyle='--', alpha=0.5, label='R-peak')
    plt.annotate('R', xy=(r_peak_time, f[int(0.3*fs)]),
                xytext=(r_peak_time+0.02, f[int(0.3*fs)]+10),
                fontsize=12, color='red')
    plt.title('Single Heartbeat — PQRST Wave Analysis')
    plt.xlabel('Time (seconds)')
    plt.ylabel('ADC Value')
    plt.legend()
    plt.grid(True)
    plt.tight_layout()
    plt.savefig('../results/experiment_1/single_beat_pqrst.png', dpi=150)
    print("Single beat plot saved to results/experiment_1/single_beat_pqrst.png")
    plt.show()
def main():
    df = pd.read_csv('../results/experiment_1/subject_6_resting_trial_1.csv')
    raw = df['ecg_value'].values.astype(float)
    timestamps = df['timestamp'].values
    fs = 533
    skip_samples = int(2 * fs)
    raw = raw[skip_samples:]
    timestamps = timestamps[skip_samples:]
    raw = np.clip(raw, np.percentile(raw, 1), np.percentile(raw, 99))
    raw = -raw  # Invert signal — electrode polarity reversed
    raw = np.clip(raw, np.percentile(raw, 1), np.percentile(raw, 99))
    filtered = full_pipeline(raw, fs=fs)
    print(f"Min: {filtered.min():.3f} Max: {filtered.max():.3f} Std: {filtered.std():.3f}")
    peaks = detect_r_peaks(filtered, fs=fs)
    bpm = calculate_bpm(peaks, fs=fs)
    hrv = compute_hrv(peaks, fs=fs)
    print(f"Peaks: {len(peaks)} BPM: {bpm}")
    if hrv:
        print(f"SDNN: {hrv['SDNN_ms']}ms RMSSD: {hrv['RMSSD_ms']}ms")
    samples = fs * 10
    t = timestamps[:samples]
    f = filtered[:samples]
    peaks_in_window = peaks[peaks < samples]
    plt.figure(figsize=(14, 5))
    plt.plot(t, f, color='green', linewidth=0.8, label='Filtered ECG')
    if len(peaks_in_window) > 0:
        plt.plot(timestamps[peaks_in_window], filtered[peaks_in_window], 'rv', markersize=10, label='R-peaks')
    plt.title(f'BPM: {bpm}')
    plt.xlabel('Time (seconds)')
    plt.ylabel('ADC Value')
    plt.legend()
    plt.grid(True)
    plt.tight_layout()
    plt.savefig('../results/experiment_1/peak_detection.png', dpi=150)
    print("\nPlot saved to results/experiment_1/peak_detection.png")
    plt.show()
    plot_single_beat(filtered, peaks, timestamps, fs=fs)

if __name__ == "__main__":
    main()

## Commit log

2026-05-16 Week 1-2: Hardware working, filters, peak detection complete
    [resting_trial_1.csv, resting_trial_2.csv]
2026-05-17 Week 2: sampling rate validated 533Hz, fs updated, quick BPM check added
2026-05-19 Update ECG signal acquisition rate to 533Hz
    Updated ECG signal acquisition rate from 500Hz to 533Hz and validated the change.
2026-05-19 Include hardware setup and electrode placement images
    Add hardware setup images to README
2026-05-23 Add resting trials 1-5 Subject 2 with header pins
    [resting_trial_1.csv, resting_trial_2.csv, resting_trial_3.csv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]
2026-05-23 Add clean ECG filtered peaks plot for website
2026-05-23 Add PQRST wave analysis plot — all 5 waves visible
2026-05-24 Add recovery trials 1-3 and complete exercise experiment data
    [exercise_trial_1.csv, exercise_trial_2.csv, recovery_trial_1.csv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]
2026-05-24 Final corrected exercise trial data — pre 90 post 108
2026-05-25 Add peak accuracy validation — 96.3% mean accuracy
    [peak_accuracy_validation.csv]
2026-05-27 Complete Experiment 2 — electrode placement study all 4 conditions
    [placement_both_off_1.csv, placement_both_off_2.csv, placement_both_off_3.csv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]
2026-05-27 Complete Experiment 3 — filter algorithm comparison
    [algorithm_comparison.csv]
2026-05-29 Add PCB schematic and layout — EasyEDA design v1.0
2026-05-29 Add system block diagram and PCB design documentation
2026-05-29 Complete GitHub README — full project documentation
2026-05-29 Add firmware, docs, experiments folders — improve repo structure
2026-06-03 Add Bland-Altman validation plot — ECG vs Apple Watch
2026-06-06 Add Subject 5 Apple Watch validation data
    [apple_watch_validation_subject5.csv]
2026-06-06 Update Bland-Altman plot — N=10 combined Subjects 4 and 5
2026-06-06 Add Subject 5 PQRST analysis, update validation plot with r and MAPE
    [subject_5_pqrst_trial.csv]
2026-06-07 Add Subject 2 Apple Watch validation — N=15 combined Bland-Altman
    [apple_watch_validation_subject2.csv]
2026-06-07 Add Subject 2 photos, updated plots, Subject 6 trial 1
    [subject_6_resting_trial_1.csv]
2026-06-09 Add KiCad PCB layout screenshot
2026-06-09 Add KiCad PCB project — Python-generated netlist, component placement, board outline
    [ECG-Biosensor-AD8232-B_Cu.gbr, ECG-Biosensor-AD8232-B_Mask.gbr, ECG-Biosensor-AD8232-B_Paste.gbr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]
2026-06-12 Fix URL in load_ecg_data function and clean up code
    [ecg_dashboard_demo.py]
2026-06-12 Fix requirements.txt, add final PCB files and gerbers
    [ECG-Biosensor-AD8232-final-B_Cu.gbr, ECG-Biosensor-AD8232-final-B_Mask.gbr, ECG-Biosensor-AD8232-final-Edge_Cuts.gbr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]
2026-06-12 Fix Streamlit dependencies
    [ecg_biosensor.dsn, ecg_biosensor2.dsn]
2026-06-12 Fix URL for loading ECG data
    [ecg_dashboard_demo.py]
2026-06-12 Fix timestamp calculation for ECG data
    [ecg_dashboard_demo.py]
